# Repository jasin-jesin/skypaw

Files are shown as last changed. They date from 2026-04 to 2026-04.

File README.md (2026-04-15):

# 🐾 SkyPaw — Quadruped Robot with Decorative Wings

> **University of Hertfordshire** · BEng Robotics & AI · Group Project 2025–2026







---

## Overview

**SkyPaw** is a 4-legged quadruped walking robot with two decorative wings, built from scratch as a university group project using the **Scrum methodology** across 6 sprints. The robot is fully **3D printed**, controlled via a **Raspberry Pi Pico H**, and features four autonomous behaviours driven by onboard sensors.

The wings serve as a predator-response display — they open automatically when fast movement is detected by the PIR sensor.

<p align="center">
  SkyPaw System Architecture
</p>

---

## Hardware Specifications

| Component | Detail |
|---|---|
| **Microcontroller** | Raspberry Pi Pico H (RP2040) |
| **Servo controller** | PCA9685 — 16-channel PWM via I2C |
| **Leg servos** | 8 × SG90 (2 per leg: hip + knee) |
| **Wing servos** | 2 × SG90 (left wing + right wing) |
| **Servo channels** | Legs: CH0–CH7 · Wings: CH8–CH9 |
| **Ultrasonic sensors** | 2 × HC-SR04 (front left + front right) |
| **Light sensors** | LDR on ADC GP26 |
| **Power supply** | 4 × AA batteries (6V rail) |
| **Frame** | Fully 3D printed PLA |
| **PWM frequency** | 50Hz · Pulse width 1–2ms |

### Pin Mapping

| Pin | Function |
|---|---|
| GP4 (SDA) | I2C to PCA9685 |
| GP5 (SCL) | I2C to PCA9685 |
| GP0 | HC-SR04 Left — Trig |
| GP1 | HC-SR04 Left — Echo |
| GP2 | HC-SR04 Right — Trig |
| GP3 | HC-SR04 Right — Echo |
| GP26 | LDR — Analogue ADC |

---

## Autonomous Behaviours

| # | Behaviour | Sensor Used | Description |
|---|---|---|---|
| 1 | **Obstacle avoidance** | HC-SR04 (×2) | Detects and steers around obstacles in path |
| 2 | **Phototaxis** | LDR | Guides robot toward a light source |
| 3 | **Predator response** | PIR | Detects fast movement, opens wings as display |
| 4 | **Random walk** | — | Explores environment in randomised directions |

---

## System Architecture

The full hardware architecture diagram is located at [`docs/system_architecture.png`](docs/system_architecture.png).

```
4 × AA (6V)
     │
     ▼
Raspberry Pi Pico H  ──(I2C)──►  PCA9685 Servo Controller
     │                                    │
     │                         ┌──────────┼──────────┐
     │                         ▼          ▼          ▼
     │                    Leg servos  Leg servos  Wing servos
     │                    CH0–CH3     CH4–CH7     CH8–CH9
     │
     ├──(GPIO GP0–GP3)──►  HC-SR04 Left + Right
     └──(ADC  GP26)────►  LDR Light Sensor
```

---

## Repository Structure

```
SkyPaw/
│
├── design/                        ← 3D CAD files, mechanical drawings
│   ├── cad_files/
│   └── assembly_drawings/
│
├── circuit/                       ← Electronics and wiring
│   ├── schematic/
│   └── wiring_diagrams/
│
├── documentation/                 ← All project documents
│   ├── system_architecture.png    ← Hardware architecture diagram
│   ├── program_flowchart.png      ← Behaviour logic flowchart
│   ├── gantt_chart.png            ← Project Gantt chart
│   ├── burndown_charts.png        ← Sprint burndown charts
│   ├── bom.xlsx                   ← Bill of materials (~£93)
│   ├── risk_register.xlsx
│   ├── sprint_plans/
│   └── meeting_minutes.docx       ← All 14 sessions Jan–Apr 2026
│
├── code/                          ← All CircuitPython source code
│   ├── code.py                    ← Main entry point
│   ├── behaviours/
│   │   ├── obstacle_avoidance.py
│   │   ├── phototaxis.py
│   │   ├── predator_response.py
│   │   └── random_walk.py
│   └── lib/                       ← CircuitPython libraries
│
└── README.md
```

---

## Sprint Timeline

| Sprint | Focus | Dates | Key Outcome |
|---|---|---|---|
| Sprint 0 | Planning & Setup | Jan 27 – Feb 3 | Concept confirmed, roles assigned |
| Sprint 1 | 3D Design | Feb 3 – Feb 17 | CAD models complete |
| Sprint 2 | 3D Printing | Feb 17 – Mar 3 | Physical frame printed |
| Sprint 3 | Electronics | Feb 24 – Mar 10 | Wiring and circuit complete |
| Sprint 4 | Programming | Mar 10 – Apr 7 | All 4 behaviours coded |
| Sprint 5 | Assembly & Testing | Mar 12 – Apr 14 | Full robot tested and signed off |

### Key Milestones

- 📅 **Jan 30** — Extra alignment session, peer teaching, concept locked
- 📦 **Feb 17** — Components received; Apikeshini joined the team
- 🔧 **Feb 24** — Tutor communication issue identified and resolved
- 🚶 **Mar 24** — **FIRST WALK ACHIEVED**
- 🧪 **Apr 9** — Full behaviour testing on assembled robot
- ✅ **Apr 14** — Final tweaking, project signed off

---

## Getting Started

### Requirements

- Raspberry Pi Pico H
- CircuitPython firmware (latest stable)
- Libraries: `adafruit_pca9685`, `adafruit_motor`, `adafruit_hcsr04`

### Setup

1. Flash CircuitPython onto the Pico H
2. Copy the `lib/` folder to the Pico's `CIRCUITPY` drive
3. Copy `code.py` to the root of `CIRCUITPY`
4. Power the robot — it will start in **random walk** mode by default

### Switching Behaviours

Edit the `BEHAVIOUR` constant at the top of `code.py`:

```python
BEHAVIOUR = "obstacle_avoidance"  # or "phototaxis", "predator", "random_walk"
```

---

## Bill of Materials

| Component | Qty | Unit Cost | Total |
|---|---|---|---|
| Raspberry Pi Pico H | 1 | £5.00 | £5.00 |
| PCA9685 servo controller | 1 | £3.50 | £3.50 |
| SG90 servo | 10 | £2.00 | £20.00 |
| HC-SR04 ultrasonic | 2 | £1.50 | £3.00 |
| LDR + resistor | 1 | £0.50 | £0.50 |
| AA battery holder (×4) | 1 | £1.50 | £1.50 |
| PLA filament | — | ~£15.00 | £15.00 |
| Jumper wires, PCB, misc | — | ~£10.00 | £10.00 |
| **Total** | | | **~£58.50** |

> Full BOM with part numbers available in [`documentation/bom.xlsx`](documentation/bom.xlsx)

---

## Team

| Name | Role |
|---|---|
| **Jasin** | Team lead, electronics, documentation |
| **Shekinah** | 3D design, assembly |
| **Ramon** | Programming, testing |
| **Savio** | Electronics, wiring |
| **Apikeshini** | Programming, documentation (joined Sprint 2) |

---

## Project Management

This project followed **Scrum** methodology with weekly sprints, managed using:

- Sprint planning documents
- Weekly meeting minutes (14 sessions total)
- Risk register
- Burndown charts per sprint
- GitHub for version control and documentation

All sprint management documents are in the [`documentation/`](documentation/) folder.

---

## License

MIT License — see [`LICENSE`](LICENSE) for details.

---

*University of Hertfordshire · BEng Robotics & AI · Group Project 2025–2026*

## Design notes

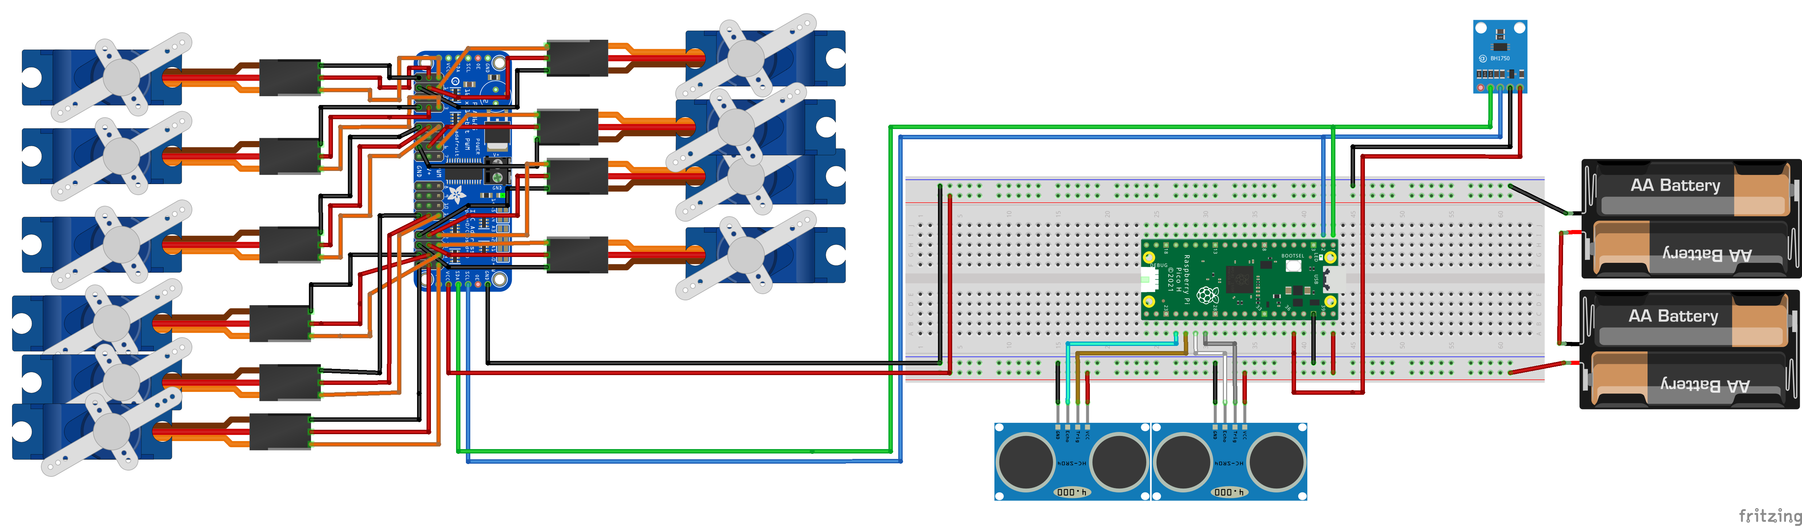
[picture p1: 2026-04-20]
designs/Skypaw_electronics_bb.png

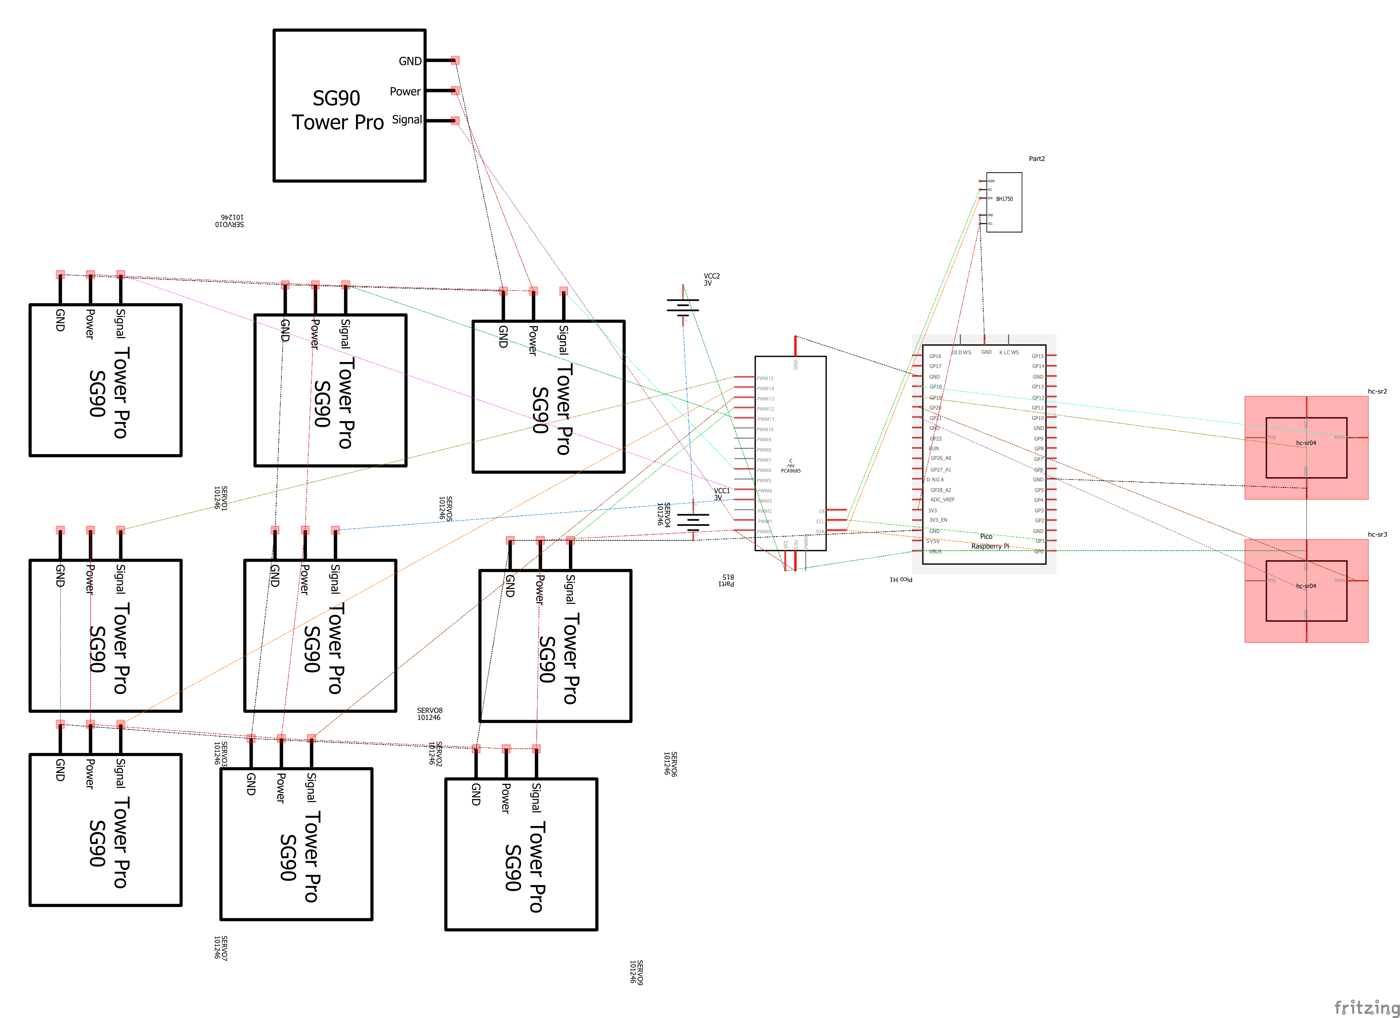
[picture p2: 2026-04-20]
designs/Skypaw_electronics_schem.png

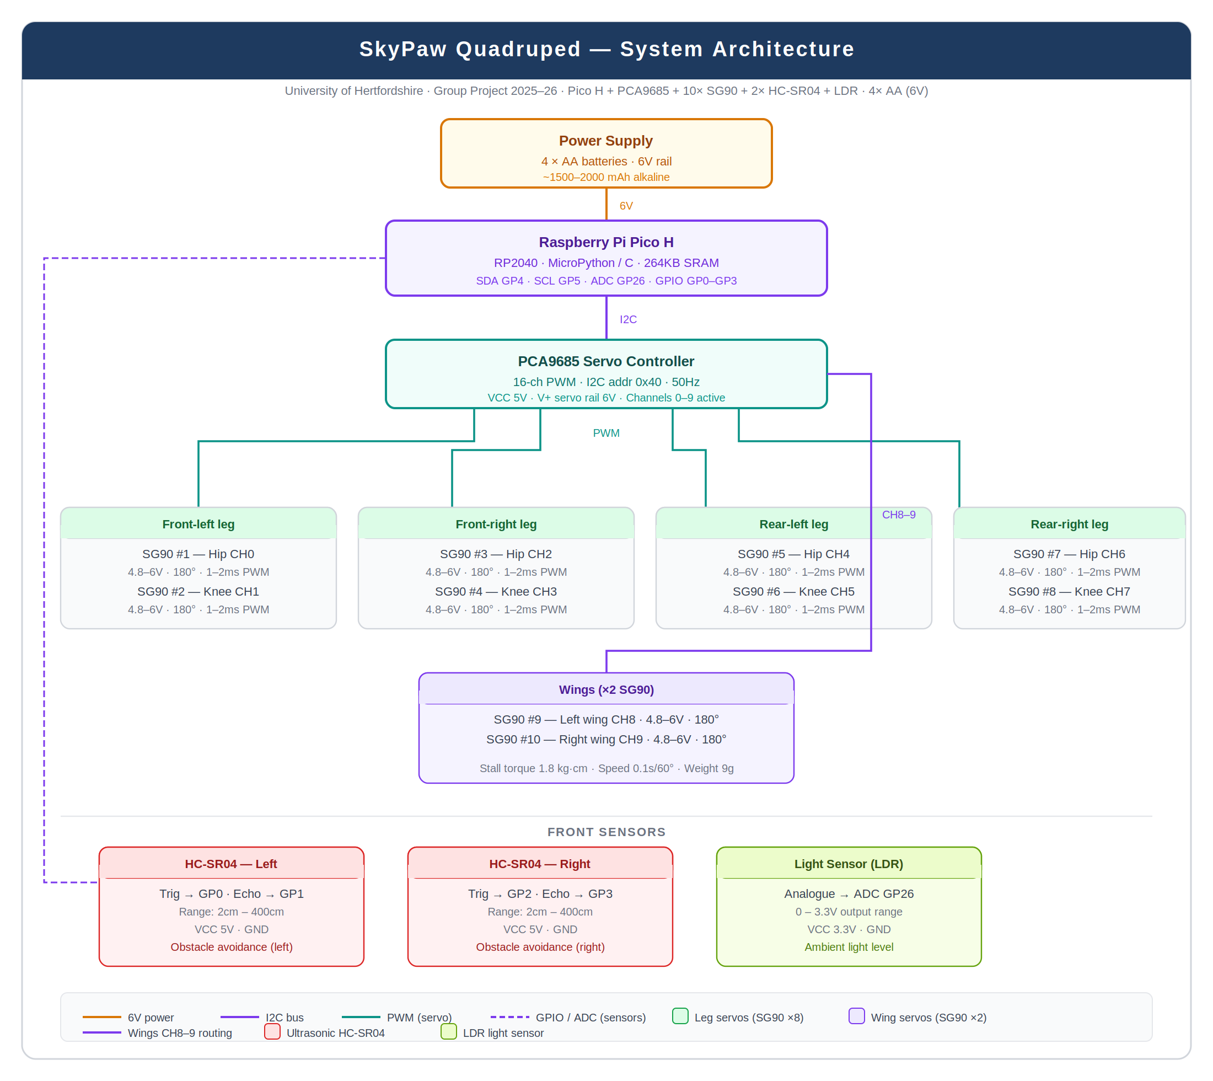
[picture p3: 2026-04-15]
documents/SkyPaw_System_Architecture.png

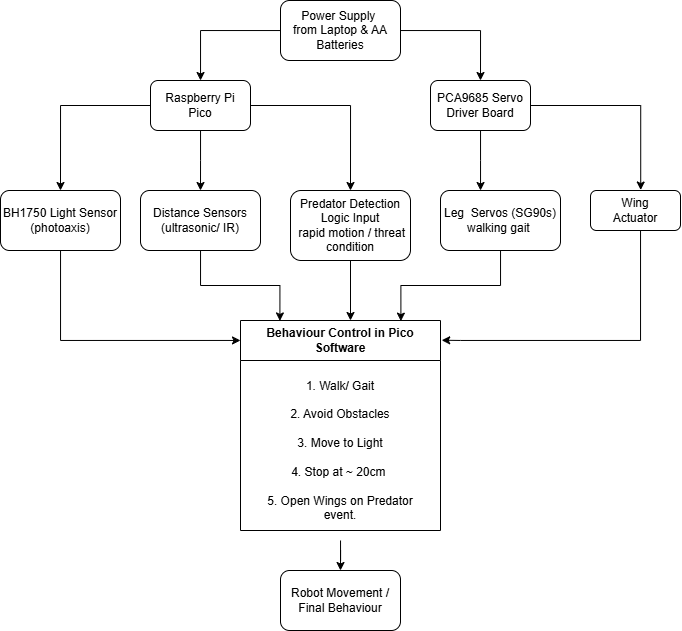
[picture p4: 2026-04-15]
documents/Circuit Diagram.drawio.png

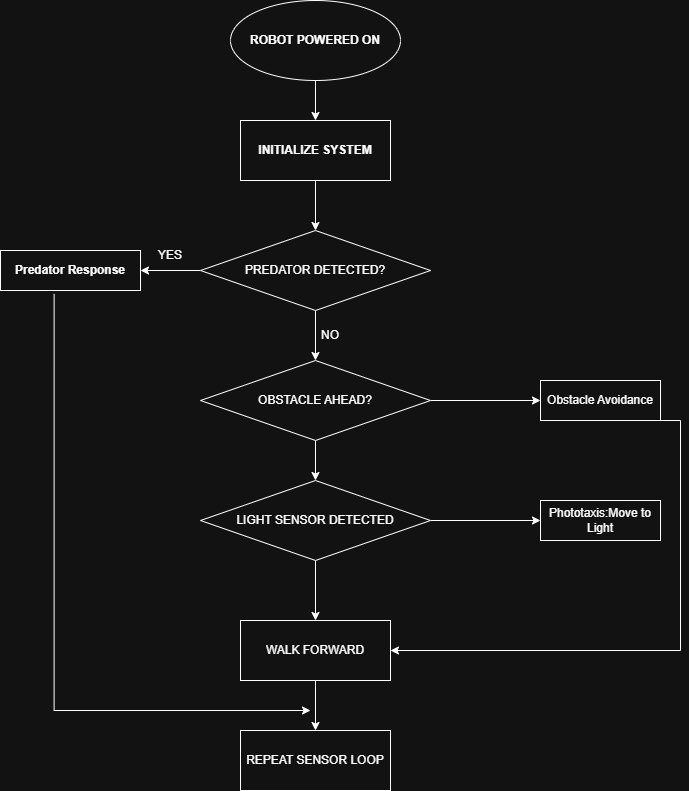
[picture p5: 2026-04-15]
documents/Moment of Robot flowchart.png

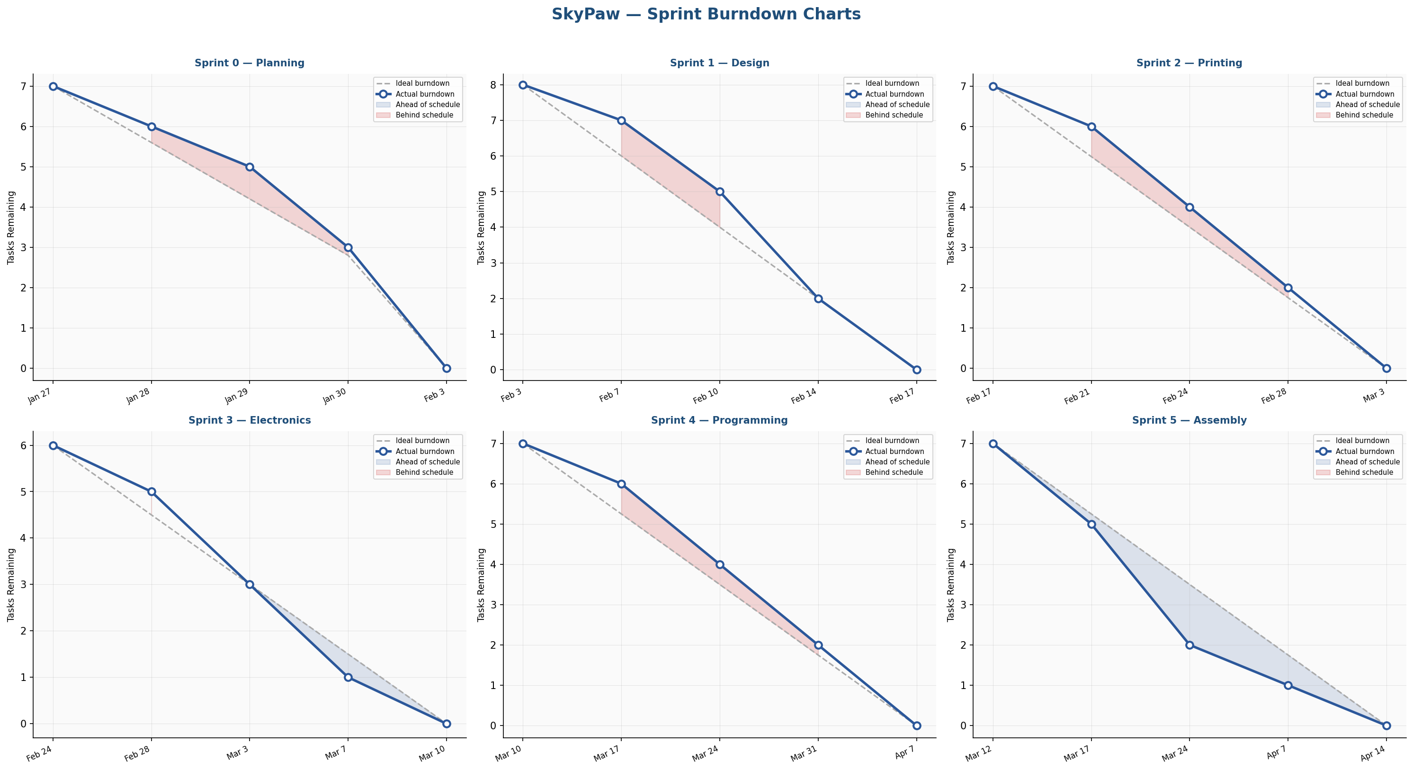
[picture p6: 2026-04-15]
documents/burndown_charts.png

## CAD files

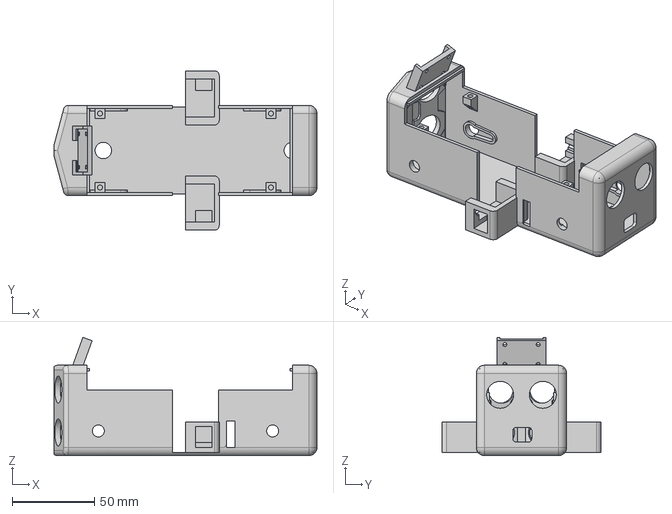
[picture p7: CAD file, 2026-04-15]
designs/Skypaw_chasis.step
160.0 x 97.0 x 71.9 mm

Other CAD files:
designs/Skypaw_wing.step

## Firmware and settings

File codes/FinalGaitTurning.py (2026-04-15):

import board
import busio
import time
import random
from adafruit_pca9685 import PCA9685
from adafruit_motor import servo

# =========================
# USER SPEED CONTROL
# =========================
SPEED = 3

# =========================
# I2C + PCA9685
# =========================
i2c = busio.I2C(board.GP1, board.GP0)
pca = PCA9685(i2c)
pca.frequency = 50

# =========================
# Servo mapping
# =========================
back_right_leg   = servo.Servo(pca.channels[0])
back_right_foot  = servo.Servo(pca.channels[1])

back_left_leg    = servo.Servo(pca.channels[2])
back_left_foot   = servo.Servo(pca.channels[4])

front_left_leg   = servo.Servo(pca.channels[12])
front_right_foot = servo.Servo(pca.channels[13])
front_right_leg  = servo.Servo(pca.channels[14])
front_left_foot  = servo.Servo(pca.channels[15])

# =========================
# Base standing pose
# =========================
BL_LEG_BASE = 150
BL_FOOT_BASE = 80

BR_LEG_BASE = 30
BR_FOOT_BASE = 100

FL_LEG_BASE = 90
FL_FOOT_BASE = 60

FR_LEG_BASE = 120
FR_FOOT_BASE = 130

# =========================
# Gait tuning
# =========================
LEG_SWING = 20
FOOT_LIFT = 20
STEP_DELAY = 0.01
BODY_PUSH = 10

# Turning tuning
TURN_INNER_SCALE = 0.45
TURN_OUTER_SCALE = 1.00

# Forward correction
FORWARD_TRIM = 6

# Stronger right turn
RIGHT_TURN_BOOST = 10

# Random zig-zag tuning
ZIGZAG_FORWARD_MIN = 3
ZIGZAG_FORWARD_MAX = 7
ZIGZAG_TURN_MIN = 1
ZIGZAG_TURN_MAX = 6
ZIGZAG_PAUSE = 0.15

# =========================
# Helpers
# =========================
def clamp_angle(a):
    if a < 0:
        return 0
    if a > 180:
        return 180
    return int(a)

def move_servo_slow(servo_obj, start, end, step=1, delay=0.01):
    delay = delay / SPEED
    step = max(1, int(step * SPEED))

    start = clamp_angle(start)
    end = clamp_angle(end)

    if start < end:
        for a in range(start, end + 1, step):
            servo_obj.angle = a
            time.sleep(delay)
        servo_obj.angle = end
    else:
        for a in range(start, end - 1, -step):
            servo_obj.angle = a
            time.sleep(delay)
        servo_obj.angle = end

def stand():
    back_left_leg.angle = BL_LEG_BASE
    back_left_foot.angle = BL_FOOT_BASE

    back_right_leg.angle = BR_LEG_BASE
    back_right_foot.angle = BR_FOOT_BASE

    front_left_leg.angle = FL_LEG_BASE
    front_left_foot.angle = FL_FOOT_BASE

    front_right_leg.angle = FR_LEG_BASE
    front_right_foot.angle = FR_FOOT_BASE

def sit():
    back_left_foot.angle = 0
    back_right_foot.angle = 180
    front_right_foot.angle = 180
    front_left_foot.angle = 0

def def_stop():
    stand()

# =========================
# Diagonal pair 1
# front_left + back_right
# =========================
def move_pair(fl_leg_target, fl_foot_target,
              br_leg_target, br_foot_target,
              fr_leg_target, bl_leg_target):

    # Lift moving pair
    move_servo_slow(front_left_foot, FL_FOOT_BASE, fl_foot_target, delay=STEP_DELAY)
    move_servo_slow(back_right_foot, BR_FOOT_BASE, br_foot_target, delay=STEP_DELAY)

    # Swing moving pair forward
    move_servo_slow(front_left_leg, FL_LEG_BASE, fl_leg_target, delay=STEP_DELAY)
    move_servo_slow(back_right_leg, BR_LEG_BASE, br_leg_target, delay=STEP_DELAY)

    # Supporting pair push body
    move_servo_slow(front_right_leg, FR_LEG_BASE, fr_leg_target, delay=STEP_DELAY)
    move_servo_slow(back_left_leg, BL_LEG_BASE, bl_leg_target, delay=STEP_DELAY)

    # Put moving pair down
    move_servo_slow(front_left_foot, fl_foot_target, FL_FOOT_BASE, delay=STEP_DELAY)
    move_servo_slow(back_right_foot, br_foot_target, BR_FOOT_BASE, delay=STEP_DELAY)

    time.sleep(0.03 / SPEED)

    # Return all legs to base
    move_servo_slow(front_left_leg, fl_leg_target, FL_LEG_BASE, delay=STEP_DELAY)
    move_servo_slow(back_right_leg, br_leg_target, BR_LEG_BASE, delay=STEP_DELAY)
    move_servo_slow(front_right_leg, fr_leg_target, FR_LEG_BASE, delay=STEP_DELAY)
    move_servo_slow(back_left_leg, bl_leg_target, BL_LEG_BASE, delay=STEP_DELAY)

# =========================
# Diagonal pair 2
# front_right + back_left
# =========================
def move_pair_2(fr_leg_target, fr_foot_target,
                bl_leg_target, bl_foot_target,
                fl_leg_target, br_leg_target):

    # Lift moving pair
    move_servo_slow(front_right_foot, FR_FOOT_BASE, fr_foot_target, delay=STEP_DELAY)
    move_servo_slow(back_left_foot, BL_FOOT_BASE, bl_foot_target, delay=STEP_DELAY)

    # Swing moving pair forward
    move_servo_slow(front_right_leg, FR_LEG_BASE, fr_leg_target, delay=STEP_DELAY)
    move_servo_slow(back_left_leg, BL_LEG_BASE, bl_leg_target, delay=STEP_DELAY)

    # Supporting pair push body
    move_servo_slow(front_left_leg, FL_LEG_BASE, fl_leg_target, delay=STEP_DELAY)
    move_servo_slow(back_right_leg, BR_LEG_BASE, br_leg_target, delay=STEP_DELAY)

    # Put moving pair down
    move_servo_slow(front_right_foot, fr_foot_target, FR_FOOT_BASE, delay=STEP_DELAY)
    move_servo_slow(back_left_foot, bl_foot_target, BL_FOOT_BASE, delay=STEP_DELAY)

    time.sleep(0.03 / SPEED)

    # Return all legs to base
    move_servo_slow(front_right_leg, fr_leg_target, FR_LEG_BASE, delay=STEP_DELAY)
    move_servo_slow(back_left_leg, bl_leg_target, BL_LEG_BASE, delay=STEP_DELAY)
    move_servo_slow(front_left_leg, fl_leg_target, FL_LEG_BASE, delay=STEP_DELAY)
    move_servo_slow(back_right_leg, br_leg_target, BR_LEG_BASE, delay=STEP_DELAY)

# =========================
# Forward gait
# =========================
def walk_forward():
    move_pair(
        fl_leg_target=FL_LEG_BASE - LEG_SWING,
        fl_foot_target=FL_FOOT_BASE - FOOT_LIFT,
        br_leg_target=BR_LEG_BASE + LEG_SWING + FORWARD_TRIM,
        br_foot_target=BR_FOOT_BASE + FOOT_LIFT,
        fr_leg_target=FR_LEG_BASE - BODY_PUSH - FORWARD_TRIM,
        bl_leg_target=BL_LEG_BASE + BODY_PUSH
    )

    move_pair_2(
        fr_leg_target=FR_LEG_BASE + LEG_SWING + FORWARD_TRIM,
        fr_foot_target=FR_FOOT_BASE + FOOT_LIFT,
        bl_leg_target=BL_LEG_BASE - LEG_SWING,
        bl_foot_target=BL_FOOT_BASE - FOOT_LIFT,
        fl_leg_target=FL_LEG_BASE + BODY_PUSH,
        br_leg_target=BR_LEG_BASE - BODY_PUSH - FORWARD_TRIM
    )
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

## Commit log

2026-03-10 Revise README for SkyPaw robot project details
    Updated project details and specifications for SkyPaw robot, including changes to the microcontroller and software. Added new tasks and clarified the role of decorative wings.
2026-04-15 Rename Circuit Diagram.drawio.png to documents/Circuit Diagram.drawio.png
2026-04-15 Rename Moment of Robot flowchart.png to documents/Moment of Robot flowchart.png
